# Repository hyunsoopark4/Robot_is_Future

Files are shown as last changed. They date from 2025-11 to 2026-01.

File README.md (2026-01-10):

# Robot_is_Future
# 🚜 ESP32 Mecanum Wheel Forklift
> **PS4 Controller-based Omnidirectional Forklift Robot**



## 📖 Overview
이 프로젝트는 **ESP32**와 **메카넘 휠(Mecanum Wheel)**을 활용한 무선 조종 지게차입니다. **PS4 컨트롤러(DualShock 4)**를 통해 블루투스로 제어하며, 전후좌우 이동뿐만 아니라 제자리 회전, 대각선 이동 등 옴니지향성 기동이 가능합니다. 

지게차의 리프트 기능은 **스텝모터(Stepper Motor)** 또는 서보모터를 사용하여 정밀하게 높이를 조절할 수 있도록 설계되었습니다.

## ✨ Key Features
* **🎮 PS4 컨트롤러 제어:** `Bluepad32` 라이브러리를 활용한 저지연 블루투스 연결
* **🔄 메카넘 휠 구동:** 4개의 TT 모터 독립 제어를 통한 전방향(Omnidirectional) 이동
* **🏗️ 리프트 메커니즘:** 스텝모터(28BYJ-48)를 활용한 포크 상승/하강 구현
* **🔋 전원 시스템:** 18650 배터리(2S) 및 TB6612FNG 모터 드라이버 사용
* **3️⃣ 3D Printed Chassis:** 직접 설계 및 3D 프린팅된 부품 사용 (`.3mf` 포함)

## 🛠️ Hardware List
| Component | Model / Note | Qty |
| :--- | :--- | :--- |
| **MCU** | ESP32 DevKit V1 | 1 |
| **Motor Driver** | TB6612FNG (Dual Motor Driver) | 2 |
| **Driving Motor** | Arduino TT Motor | 4 |
| **Lift Motor** | 28BYJ-48 Stepper Motor + ULN2003 Driver | 1 |
| **Wheels** | 60mm Mecanum Wheels | 4 |
| **Power** | 18650 Li-ion Battery (2S, 7.4V) | 2 |
| **Regulator** | LTC-3780 | 1 |
| **Controller** | PS4 DualShock 4 | 1 |

## 🔌 Pinout & Wiring
소스 코드(`ESP32_Mecanum_PS4.ino`)에 정의된 핀맵입니다.

### 🚗 Drive Motors (TB6612FNG)
| Motor Position | PWM Pin | IN1 | IN2 | Channel |
| :--- | :--- | :--- | :--- | :--- |
| **Right Front (RF)** | GPIO 32 | GPIO 25 | GPIO 33 | 0 |
| **Right Rear (RR)** | GPIO 13 | GPIO 27 | GPIO 14 | 1 |
| **Left Front (LF)** | GPIO 23 | GPIO 22 | GPIO 21 | 2 |
| **Left Rear (LR)** | GPIO 19 | GPIO 18 | GPIO 5  | 3 |
| **Standby (Common)** | GPIO 26 | - | - | - |

### 🏗️ Lift Motor (Stepper 28BYJ-48)
* **IN1:** GPIO 15
* **IN3:** GPIO 4
* **IN2:** GPIO 2
* **IN4:** GPIO 16
* *(Note: Stepper library uses IN1-IN3-IN2-IN4 sequence)*

## 🎮 Controls (PS4 Mapping)

| Button / Stick | Action | Description |
| :--- | :--- | :--- |
| **Left Stick (X/Y)** | Move | 전후좌우 및 대각선 이동 |
| **Right Stick (X)** | Rotate | 제자리 회전 (Turn Left/Right) |
| **Triangle (△)** | Lift UP | 포크 상승 |
| **Cross (X)** | Lift DOWN | 포크 하강 |

![Controller Mapping] 

## 🖨️ 3D Models
이 프로젝트의 기구부는 3D 프린터로 제작되었습니다.
* **File Format:** `.3mf` (Bambu Lab / Prusa Slicer compatible)
* **Included Parts:** Chassis, Wheels mounts, Fork mechanism
> **Preview:**


## 🚀 Upcoming Upgrade: N20 Motor Retrofit
현재 버전은 아두이노 TT 모터(노란색 기어드 모터)를 기반으로 제작되었으나, 더욱 정밀한 제어를 위해 **N20 메탈 기어 모터**로 업그레이드할 예정입니다.

### 🛑 Why Upgrade? (TT Motor Limitations)
* **불규칙한 데드존(Deadzone):** 저가형 TT 모터는 개체마다 기동 시작 PWM 값이 달라(60~90), 저속 주행 시 특정 바퀴만 회전하지 않는 문제가 발생합니다.
* **정밀 제어의 어려움:** 지게차 특성상 미세한 움직임이 필수적인데, TT 모터는 마찰력으로 인해 저속에서 부드러운 제어가 어렵습니다.

### 🛠️ Solution: N20 Motor & Custom Chassis
이를 해결하기 위해 다음과 같은 업그레이드를 진행하고 있습니다.
1.  **Motor Change:** **N20 Gear Motor (6V)**로 교체하여 메탈 기어의 우수한 내구성과 거의 없는 데드존(Deadzone)을 확보합니다.
2.  **Custom Modeling:** 기존 TT 모터용 섀시 대신, N20 모터 규격에 최적화된 **전용 프레임(Chassis)**을 직접 모델링하여 적용합니다.
3.  **Result:** 4개 바퀴의 완벽한 속도 동기화와 부드러운 옴니지향성 주행을 구현합니다.

*(N20 버전의 3D 모델링 파일과 코드는 추후 업데이트될 예정입니다.)*

## 💻 How to Install
1.  Install **Arduino IDE**.
2.  Install **ESP32 Board Manager** (`Espressif Systems`).
3.  Install Required Libraries:
    * [cite_start]`Bluepad32` by Ricardo Quesada [cite: 1]
    * [cite_start]`Stepper` (Built-in) [cite: 1]
4.  Open `ESP32_Mecanum_PS4.ino`.
5.  Select your ESP32 board and Upload.
6.  Open Serial Monitor (115200 baud).
7.  Press the **EN** button on ESP32 to reset and start Bluetooth pairing.
8.  Connect your PS4 Controller (Hold Share + PS button to pair).

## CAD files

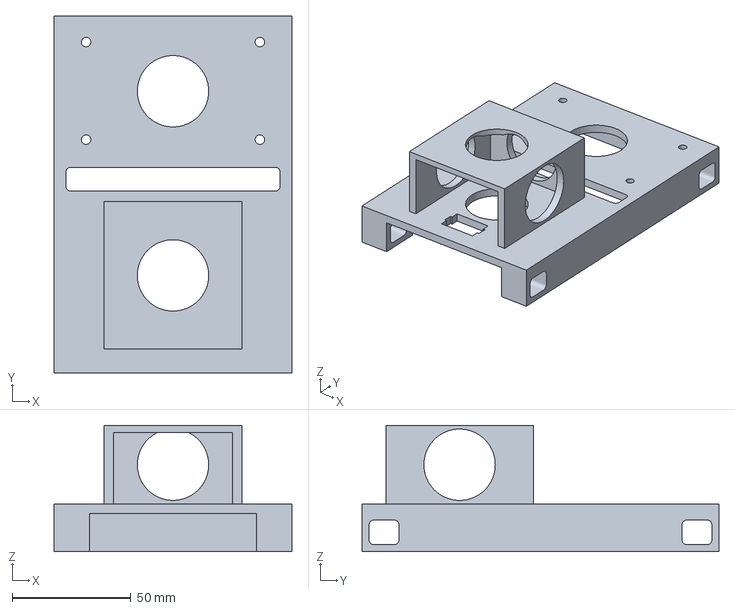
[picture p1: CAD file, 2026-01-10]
Mecanum wheel forklinft for N20.3mf
100.0 x 150.0 x 53.0 mm

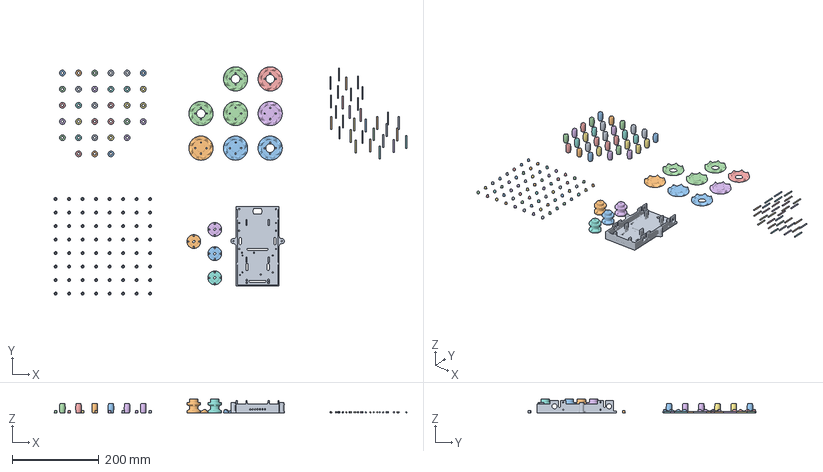
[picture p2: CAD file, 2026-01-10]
Mecanum wheel forklinft for TT.3mf
816.0 x 527.9 x 32.0 mm
default.stl_1
MECW000P004-01 Roller rim.stl x 64
MECW.000P003-02 Motor coupler for geared DC motor.STL x 4
MECW.000P001-01 Inner ring.STL x 4
MECW.000P005-01 Roller.STL x 32
MECW.000P002-01 Outer ring.STL x 4
3X30 봉 x 32

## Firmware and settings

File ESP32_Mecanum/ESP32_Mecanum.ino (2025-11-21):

/*
 * ESP32-S3 DevKitC-1 및 TB6612 2개용 메카넘 휠 제어 코드
 * * 제공된 Mecanum_wheel.ino 파일의 로직(전진/정지)을 기반으로 재작성되었습니다.
 * 사용자가 지정한 새 핀 매핑을 적용했습니다.
 */

// 전진 시 속도 (0~255)
int speedValue = 200;

// -----------------------------------------------------------------
// 1. 핀 정의 (사용자 지정 매핑 적용)
// -----------------------------------------------------------------

// 공통 Standby 핀
const int STBY = 4; // 사용자가 GPIO 4로 지정

// 모터 1: Front Left (FL) - Driver 1, Channel A
const int PWMA_PIN = 1;  // (구 GPIO 10 -> 검은색 핀 4)
const int AIN1 = 2;  // (구 GPIO 11 -> 검은색 핀 5)
const int AIN2 = 42; // (구 GPIO 12 -> 검은색 핀 6)

// 모터 2: Rear Left (RL) - Driver 1, Channel B
const int PWMB_PIN = 41; // (구 GPIO 13 -> 검은색 핀 7)
const int BIN1 = 40; // (구 GPIO 14 -> 검은색 핀 8)
const int BIN2 = 39; // (구 GPIO 15 -> 검은색 핀 9)

// 모터 3: Front Right (FR) - Driver 2, Channel A
const int PWMC_PIN = 38; // (구 GPIO 16 -> 검은색 핀 10)
const int CIN1 = 37; // (구 GPIO 17 -> 검은색 핀 11)
const int CIN2 = 36; // (구 GPIO 18 -> 검은색 핀 12)

// 모터 4: Rear Right (RR) - Driver 2, Channel B
const int PWMD_PIN = 35; // (구 GPIO 19 -> 검은색 핀 13)
// 🚨 위험! GPIO 0은 부팅 핀입니다. 다른 핀으로 변경하는 것을 강력히 권장합니다.
const int DIN1 = 0;  // (구 GPIO 38 -> 검은색 핀 14)
const int DIN2 = 45; // (구 GPIO 39 -> 검은색 핀 15)

// -----------------------------------------------------------------
// 2. ESP32 LEDC (PWM) 설정
// -----------------------------------------------------------------
const int PWM_FREQ = 5000;    // 5kHz PWM 주파수
const int PWM_RESOLUTION = 8; // 8비트 해상도 (0-255)

// 각 모터에 대한 PWM 채널 할당 (0~7)
const int PWM_CHAN_FL = 0; // Front Left
const int PWM_CHAN_RL = 1; // Rear Left
const int PWM_CHAN_FR = 2; // Front Right
const int PWM_CHAN_RR = 3; // Rear Right


void setup() {
  // [cite: 3] 핀 모드 설정 (OUTPUT)
  pinMode(STBY, OUTPUT);
  
  pinMode(AIN1, OUTPUT);
  pinMode(AIN2, OUTPUT);
  pinMode(BIN1, OUTPUT);
  pinMode(BIN2, OUTPUT);
  pinMode(CIN1, OUTPUT);
  pinMode(CIN2, OUTPUT);
  pinMode(DIN1, OUTPUT);
  pinMode(DIN2, OUTPUT);
  
  // PWM 핀들은 ledcAttachPin이 자동으로 OUTPUT 설정함 (pinMode 불필요)

  // ESP32 LEDC(PWM) 시스템 설정
  ledcSetup(PWM_CHAN_FL, PWM_FREQ, PWM_RESOLUTION);
  ledcSetup(PWM_CHAN_RL, PWM_FREQ, PWM_RESOLUTION);
  ledcSetup(PWM_CHAN_FR, PWM_FREQ, PWM_RESOLUTION);
  ledcSetup(PWM_CHAN_RR, PWM_FREQ, PWM_RESOLUTION);

  // PWM 핀을 LEDC 채널에 할당
  ledcAttachPin(PWMA_PIN, PWM_CHAN_FL);
  ledcAttachPin(PWMB_PIN, PWM_CHAN_RL);
  ledcAttachPin(PWMC_PIN, PWM_CHAN_FR);
  ledcAttachPin(PWMD_PIN, PWM_CHAN_RR);

  // 모터 드라이버 활성화
  digitalWrite(STBY, HIGH);
  
  // [cite: 2] (AFMotor 라이브러리 부분을 제외하고 setup 로직 비어있음)
}

void loop() {
  // [cite: 4] 1️⃣ 전진 (3초)
  forward();
  delay(3000);

  // [cite: 4] 2️⃣ 정지 (3초)
  stopMotors();
  delay(3000);
}

// [cite: 5] 전진 함수 (TB6612 로직 적용)
void forward() {
  // 메카넘휠 '전진'은 4개 모터가 모두 같은 방향으로 회전합니다.
  // (만약 반대로 도는 모터가 있다면 해당 모터의 IN1, IN2를 교체)
  
  // FL: 정방향
  digitalWrite(AIN1, HIGH);
  digitalWrite(AIN2, LOW);
  ledcWrite(PWM_CHAN_FL, speedValue);

  // RL: 정방향
  digitalWrite(BIN1, HIGH);
  digitalWrite(BIN2, LOW);
  ledcWrite(PWM_CHAN_RL, speedValue);

  // FR: 정방향
  digitalWrite(CIN1, HIGH);
  digitalWrite(CIN2, LOW);
  ledcWrite(PWM_CHAN_FR, speedValue);

  // RR: 정방향
  digitalWrite(DIN1, HIGH);
  digitalWrite(DIN2, LOW);
  ledcWrite(PWM_CHAN_RR, speedValue);
}

// [cite: 6] 정지 함수
void stopMotors() {
  // PWM을 0으로 설정하여 모터 정지 (Coast)
  ledcWrite(PWM_CHAN_FL, 0);
  ledcWrite(PWM_CHAN_RL, 0);
  ledcWrite(PWM_CHAN_FR, 0);
  ledcWrite(PWM_CHAN_RR, 0);
}

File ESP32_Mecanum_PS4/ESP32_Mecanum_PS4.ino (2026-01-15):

#include <Bluepad32.h>
#include <Stepper.h>             // 스텝모터 라이브러리 추가
#include "soc/soc.h"             
#include "soc/rtc_cntl_reg.h"    

// ================================================================
// 1. 메카넘휠 핀 정의 (기존 유지)
// ================================================================
const int STBY_PIN = 26;
// 오른쪽
const int RF_PWM_PIN = 32; const int RF_IN1_PIN = 25; const int RF_IN2_PIN = 33;
const int RR_PWM_PIN = 13; const int RR_IN1_PIN = 27; const int RR_IN2_PIN = 14;
// 왼쪽
const int LF_PWM_PIN = 23; const int LF_IN1_PIN = 22; const int LF_IN2_PIN = 21;
const int LR_PWM_PIN = 19; const int LR_IN1_PIN = 18; const int LR_IN2_PIN = 5;

// ================================================================
// 2. 스텝모터 핀 정의 (새로 추가!)
// ================================================================
// 28BYJ-48 모터는 1바퀴에 2048 스텝
const int STEPS_PER_REV = 2048; 

// 남는 핀 할당 (IN1, IN3, IN2, IN4 순서 중요!)
// ULN2003 드라이버에 연결할 핀들: 15, 2, 4, 16
Stepper forkStepper(STEPS_PER_REV, 15, 2, 4, 16); 

// ================================================================
// 3. 설정 변수
// ================================================================
const int PWM_FREQ = 5000;
const int PWM_RES = 8;
const int CH_RF = 0; const int CH_RR = 1; 
const int CH_LF = 2; const int CH_LR = 3; 
const int DEADZONE = 30;

unsigned long lastDebugTime = 0;
ControllerPtr myControllers[BP32_MAX_GAMEPADS];

// ================================================================
// 4. 모터 구동 함수들
// ================================================================
void driveMotor(int channel, int in1, int in2, int speed) {
  speed = constrain(speed, -255, 255);
  if (speed > 0) {
    digitalWrite(in1, HIGH); digitalWrite(in2, LOW);
    ledcWrite(channel, speed);
  } else if (speed < 0) {
    digitalWrite(in1, LOW); digitalWrite(in2, HIGH);
    ledcWrite(channel, abs(speed));
  } else {
    digitalWrite(in1, LOW); digitalWrite(in2, LOW);
    ledcWrite(channel, 0);
  }
}

// 지게차 포크 제어 함수 (스텝모터)
void processForkLift(ControllerPtr ctl) {
  // 스텝모터 속도 설정 (RPM). 너무 빠르면 탈조나서 안 돔. 10~15 추천.
  forkStepper.setSpeed(10); 

  // 세모(Triangle) 버튼: 0x0008 -> 올리기
  if (ctl->buttons() & 0x0008) {
    // 루프가 도는 동안 조금씩 움직임 (블로킹 방지를 위해 작은 값)
    forkStepper.step(50); 
    if (millis() - lastDebugTime > 500) Serial.println(">> 포크 상승 중 (UP)");
  }
  
  // 엑스(Cross) 버튼: 0x0001 -> 내리기
  if (ctl->buttons() & 0x0001) {
    forkStepper.step(-50); // 반대 방향
    if (millis() - lastDebugTime > 500) Serial.println(">> 포크 하강 중 (DOWN)");
  }
  
  // 버튼 안 누르면? step() 함수 호출 안 하니까 자동으로 멈춰있음 (Hold 토크 발생)
  // 단, 스텝모터 드라이버는 전기를 계속 먹고 있음.
}

void processMecanumMovement(ControllerPtr ctl) {
  int lx = ctl->axisX();
  int ly = ctl->axisY();
  int rx = ctl->axisRX(); 

  if (abs(lx) < DEADZONE) lx = 0;
  if (abs(ly) < DEADZONE) ly = 0;
  if (abs(rx) < DEADZONE) rx = 0;

  int y = map(ly, -512, 512, 255, -255); 
  int x = map(lx, -512, 512, -255, 255); 
  int turn = map(rx, -512, 512, -255, 255);

  int fl = y + x + turn;
  int fr = y - x - turn;
  int rl = y - x + turn;
  int rr = y + x - turn;

  driveMotor(CH_LF, LF_IN1_PIN, LF_IN2_PIN, fl);
  driveMotor(CH_RF, RF_IN1_PIN, RF_IN2_PIN, fr);
  driveMotor(CH_LR, LR_IN1_PIN, LR_IN2_PIN, rl);
  driveMotor(CH_RR, RR_IN1_PIN, RR_IN2_PIN, rr);
}

// ================================================================
// 5. Bluepad32 콜백
// ================================================================
void onConnectedController(ControllerPtr ctl) {
  for (int i = 0; i < BP32_MAX_GAMEPADS; i++) {
    if (myControllers[i] == nullptr) {
      Serial.printf("CALLBACK: Controller connected, index=%d\n", i);
      myControllers[i] = ctl;
      return;
    }
  }
}

void onDisconnectedController(ControllerPtr ctl) {
  for (int i = 0; i < BP32_MAX_GAMEPADS; i++) {
    if (myControllers[i] == ctl) {
      Serial.printf("CALLBACK: Controller disconnected from index=%d\n", i);
      myControllers[i] = nullptr;
      driveMotor(CH_RF, RF_IN1_PIN, RF_IN2_PIN, 0);
      driveMotor(CH_RR, RR_IN1_PIN, RR_IN2_PIN, 0);
      driveMotor(CH_LF, LF_IN1_PIN, LF_IN2_PIN, 0);
      driveMotor(CH_LR, LR_IN1_PIN, LR_IN2_PIN, 0);
      return;
    }
  }
}

void processControllers() {
  for (auto myController : myControllers) {
    if (myController && myController->isConnected() && myController->hasData()) {
      if (myController->isGamepad()) {
        processMecanumMovement(myController); // 바퀴 제어
        processForkLift(myController);        // 지게차 포크 제어
      }
    }
  }
}

// ================================================================
// 6. Setup & Loop
// ================================================================
void setup() {
  Serial.begin(115200);
  WRITE_PERI_REG(RTC_CNTL_BROWN_OUT_REG, 0);

  pinMode(STBY_PIN, OUTPUT);
  // 메카넘 핀 설정
  pinMode(RF_IN1_PIN, OUTPUT); pinMode(RF_IN2_PIN, OUTPUT);
  pinMode(RR_IN1_PIN, OUTPUT); pinMode(RR_IN2_PIN, OUTPUT);
  pinMode(LF_IN1_PIN, OUTPUT); pinMode(LF_IN2_PIN, OUTPUT);
  pinMode(LR_IN1_PIN, OUTPUT); pinMode(LR_IN2_PIN, OUTPUT);

  // 메카넘 PWM 설정
  ledcSetup(CH_RF, PWM_FREQ, PWM_RES);
  ledcSetup(CH_RR, PWM_FREQ, PWM_RES);
  ledcSetup(CH_LF, PWM_FREQ, PWM_RES);
  ledcSetup(CH_LR, PWM_FREQ, PWM_RES);
  ledcAttachPin(RF_PWM_PIN, CH_RF);
  ledcAttachPin(RR_PWM_PIN, CH_RR);
  ledcAttachPin(LF_PWM_PIN, CH_LF);
  ledcAttachPin(LR_PWM_PIN, CH_LR);

  digitalWrite(STBY_PIN, HIGH);

  // 스텝모터는 Stepper 라이브러리가 알아서 핀 설정 해줌. 
  // 단, 충돌 방지를 위해 명시적으로 초기화해주고 싶으면 아래 주석 해제
  /*
  pinMode(15, OUTPUT); pinMode(4, OUTPUT); 
  pinMode(2, OUTPUT); pinMode(16, OUTPUT);
  */

  Serial.printf("Firmware: %s\n", BP32.firmwareVersion());
  BP32.setup(&onConnectedController, &onDisconnectedController);
  BP32.forgetBluetoothKeys();
  BP32.enableVirtualDevice(false);
  
  Serial.println("Ready! Mecanum + Forklift Mode");
}

void loop() {
  bool dataUpdated = BP32.update();
  if (dataUpdated) processControllers();
  // 스텝모터가 부드럽게 돌려면 delay가 너무 길면 안됨. 짧게 조정.
  delay(1); 
}

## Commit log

2025-11-21 Add download links for ESP32 package indexes
2025-11-21 EPS32 메카넘휠 동작 확인
2025-12-26 version1.0
    first PS4 - ESP32 Mecanum wheel fork lift
2026-01-10 Enhance README with project details and instructions
    Added detailed project overview, features, hardware list, wiring, controls, 3D models, and installation instructions for the ESP32 Mecanum Wheel Forklift.
2026-01-10 TT , N20 motor version.
    N20 version is developing.. because TT motors are not accurate.
    [Mecanum wheel forklinft for N20.3mf, Mecanum wheel forklinft for TT.3mf]
2026-01-15 Version 2.0
    using N20 motor
    new frame
